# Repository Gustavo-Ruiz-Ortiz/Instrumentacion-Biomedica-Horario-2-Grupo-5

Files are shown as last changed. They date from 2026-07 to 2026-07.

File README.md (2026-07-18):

# Instrumentacion-Biomedica-Horario-2-Grupo-5

Sistema portátil de triaje cardiopulmonar con corrección por altitud - HealthyPi 5 / RP2040


## Tabla de contenidos

- [Equipo](#equipo)
- [Descripción del proyecto](#descripción-del-proyecto)
- [Problema que resuelve](#problema-que-resuelve)
- [Características principales](#características-principales)
- [Arquitectura del sistema](#arquitectura-del-sistema)
- [Stack tecnológico](#stack-tecnológico)
- [Estructura del repositorio](#estructura-del-repositorio)
- [Instalación y uso](#instalación-y-uso)
- [Resultados de validación](#resultados-de-validación)
- [Roadmap](#roadmap)

---
## Equipo — Grupo 5

| Integrante | Aporte principal |
|---|---|
| Aldo David Manturano Lopez | Desarrollo de la adquisición de señales, impresión 3D y electrónica del dispositivo|
| David Eddy Aguilar Yahuana | Desarrollo de la adquisición de señales, soporte bibliográfico |
| Juan Raul Ramirez Mendoza | Desarrollo de página web y filtrado de señales |
| Alejandra Ivonne Gamarra Leyva | Desarrollo del contexto de uso, problemática y justificación bibliográfica, lista de exigencias, diseño y modelado 3D del enclosure.|
| Davidt Brayamn Fernandez Bernaola | Desarrollo del contexto problemático y su estructura de funciones general, además de ello, gestionar el uso del dispositivo en escenarios de uso real.|
| Gustavo Andre Ruiz Ortiz | Programación e integración de sensores; flasheo y reprogramación del firmware (Python y Zephyr) para el ajuste de lectura de altitud y la reinterpretación de SpO2 según altitud; diseño e implementación del filtrado digital de señales, y ejecución de las pruebas de validación de la parte electrónica del sistema. Desarrollo del repositorio de GitHub. |

---

## Descripción del proyecto

Dispositivo portátil, autónomo y totalmente offline para el triaje cardiopulmonar en puestos de salud rurales de altura (>2500 msnm), desarrollado sobre la plataforma HealthyPi 5 (RP2040). Adquiere ECG, PPG/SpO2 y frecuencia respiratoria derivada, y reinterpreta automáticamente los valores según la altitud real del punto de atención, evitando falsas alarmas de hipoxia propias de los monitores calibrados a nivel del mar.

Proyecto desarrollado en el curso de Instrumentación Biomédica, Universidad Peruana Cayetano Heredia (UPCH) — Grupo 5.

## Problema que resuelve

Los puestos de salud rurales altoandinos enfrentan dos limitaciones simultáneas que ningún equipo comercial resuelve en conjunto:

| Limitación | Consecuencia |
|---|---|
| Monitores calibrados a nivel del mar | Falsas alarmas de hipoxia en población aclimatada a la altura |
| Infraestructura eléctrica y conectividad inestables/inexistentes | Los equipos dependientes de nube, WiFi o smartphone no son viables |

## Características principales

- ECG (derivación II de Einthoven) mediante chip MAX30001
- PPG / SpO2 mediante chip AFE4400 (660 nm rojo / 905 nm infrarrojo)
- Frecuencia respiratoria derivada del ECG por neumografía de impedancia transtorácica, sin sensores adicionales
- Corrección automática por altitud en tiempo real (sensor atmosférico BME280) usando percentiles poblacionales de referencia
- Operación 100% offline: visualización en pantalla TFT + almacenamiento local en MicroSD
- Plataforma web de post-análisis en Python/Streamlit con filtrado digital de señal (Notch IIR 60 Hz + Butterworth pasa-bajas) y control de acceso por token OTP
- Batería de Litio 3.7V/2500 mAh — 17 horas de autonomía (~200 sesiones de triaje)
- Diseño conforme a IEC 60601-1-11 (seguridad eléctrica en entornos sin conexión a tierra confiable)
- Enclosure diseñado en Fusion 360 e impreso en 3D (PLA)

## Arquitectura del sistema



## Stack tecnológico

| Capa | Tecnología |
|---|---|
| Microcontrolador | RP2040 (HealthyPi 5) |
| Firmware | Zephyr RTOS |
| Adquisición biopotenciales | MAX30001 |
| Adquisición PPG/SpO2 | AFE4400 |
| Sensor ambiental | BME280 (altitud) |
| Almacenamiento embebido | MicroSD |
| Post-procesamiento | Python, filtros digitales (Notch IIR, Butterworth) |
| Interfaz de usuario web | Streamlit |
| Seguridad de acceso | Tokens OTP |
| Diseño mecánico | Fusion 360 + impresión 3D (PLA) |
| Normativa | IEC 60601-1-11 |

## Estructura del repositorio

```
Instrumentacion-Biomedica-Horario-2-Grupo-5/
├── firmware/            # Código Zephyr para HealthyPi 5 (RP2040)
│   ├── src/
│   └── boards/
├── interfaz-python/     # Aplicación Streamlit de post-análisis
│   ├── app.py
│   ├── filtros.py
│   └── auth_otp.py
├── diseño-mecanico/     # Archivos Fusion 360 / STL del enclosure
├── docs/                # Informes, diagramas y datasheets
│   ├── Informe4_g5.docx
│   └── Informe5_6_Grupo5.docx
├── resultados/          # Capturas de pruebas de validación (OpenView 2)
├── .gitignore
└── README.md
```

## Instalación y uso

### Firmware (Zephyr / RP2040)

```bash
git clone https://github.com/Gustavo-Ruiz-Ortiz/Instrumentacion-Biomedica-Horario-2-Grupo-5.git
cd Instrumentacion-Biomedica-Horario-2-Grupo-5/firmware
west build -b healthypi5 .
west flash
```

### Interfaz Python (post-análisis)

```bash
cd interfaz-python
python -m venv .venv
source .venv/bin/activate      # Windows: .venv\Scripts\activate
pip install -r requirements.txt
streamlit run app.py
```

## Resultados de validación

Prueba de adquisición en banco (5 min continuos, sujeto sano, línea base a nivel del mar):

| Señal | Resultado | Método |
|---|---|---|
| ECG | 92 BPM estable | Detección de intervalo R-R, amplitud promedio 1.2 mV |
| SpO2 | 98% | PPG, sensor de pinza dactilar |
| Frecuencia respiratoria | 41 RPM | Neumografía por impedancia transtorácica derivada del ECG |

Se caracterizó además un artefacto de movimiento inducido intencionalmente, validando la etapa de filtrado digital implementada en la interfaz Python.

## Roadmap

- [ ] Filtros adicionales para artefactos de movimiento en PPG
- [ ] Validación clínica con mayor número de pacientes
- [ ] Estudio de mercado formal
- [ ] Evaluación de manufactura escalable del enclosure
- [ ] Trámite de protección de la invención ante la OPI-UPCH

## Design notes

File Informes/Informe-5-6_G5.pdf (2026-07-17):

## UNIVERSIDAD PERUANA CAYETANO HEREDIA

## INGENIERÍA BIOMÉDICA

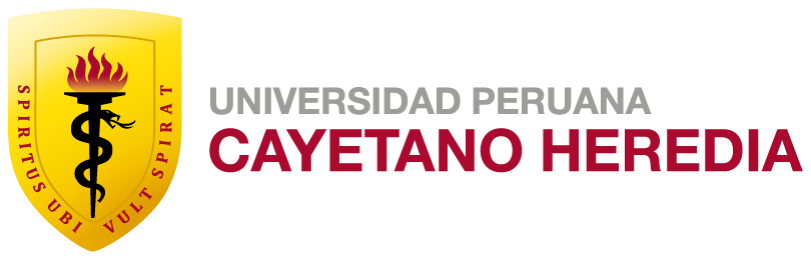
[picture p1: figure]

# PRÁCTICA DE INSTRUMENTACIÓN BIOMÉDICA

## Presentación del circuito impreso de la solución propuesta (PCB) y Solicitud de fabricación y Presentación final del modelo 3D del sistema completo [Práctica N°5 y N°6]

GRUPO N°: 5

Nombre de los Integrantes y código:

# - Aldo David, Manturano Lopez - 72387388 - David Eddy, Aguilar Yahuana - 71421807 - Juan Raul, Ramirez Mendoza - 72642526 - Alejandra Ivonne, Gamarra Leyva - 72771921 - Davidt Brayamn, Fernandez Bernaola - 72165022 - Gustavo Andre, Ruiz Ortiz - 72899306

2026 -1

### 1. Integración del sistema de diseño contextual

1.1. Problema clínico- tecnológico

Los puestos de salud rurales altoandinos carecen de especialistas y equipos

biomédicos calibrados para la fisiología de altura, imposibilitando un triaje

cardiopulmonar oportuno, por lo que exige un sistema portátil, autónomo y

adaptativo que optimice la toma de decisiones del personal no especialista en

el punto de atención.

1.2. Usuario objetivo y contexto de uso
1.2.1. Usuario paciente

Adultos de entre 18 y 60 años residentes de zonas altoandinas (2500 -

4000) msnm. Asimismo, debe ser originario de la localidad o demostrar

una residencia continua mayor a un año, asegurando que su organismo

haya completado los mecanismos de aclimatación crónica.

1.2.2. Usuario operador

Personal de salud de primer nivel de atención (técnicos en enfermería

o enfermeros rurales) sin especialización en cardiología o neumología.

1.2.3. Contexto de uso

El dispositivo está diseñado para operar en los establecimientos del

Primer Nivel de Atención (Categorías I-1 al I-4) en zonas rurales

altoandinas para brindar chequeos preventivos y triaje rápido.

1.3. Variables fisiológicas seleccionadas
1.3.1. Frecuencia cardiaca y frecuencias respiratoria

Tras analizar el artículo sobre los valores fisiológicos en la región de

Cajamarca y contrastarlos con los rangos normales estándar

establecidos por instituciones como la Cleveland Clinic, se concluye

que existe una notable adaptación de la frecuencia respiratoria (FR) y

frecuencia cardíaca (FC) en habitantes con 1 año mayor de estancia

en una localidad.

De acuerdo a la FR según la referencia de la Cleveland Clinic, el rango

normal para un adulto es de 12 a 18 respiraciones por minuto [1]. Al

observar la Tabla 4 del artículo, se evidencia que en altitudes

moderadas como 1,294 msnm, la media es de 17.53. Aunque a

altitudes mayores como 3,502 msnm la media sube ligeramente a

20.32, los valores se mantienen muy cerca de los límites superiores de

la normalidad estándar [2]. Esto sugiere que, tras más de un año de

residencia, la aclimatación permite que la FR no se dispare de forma

patológica. Por otro lado, la frecuencia cardiaca su rango normal

estándar se sitúa entre 60 y 100 latidos por minuto, los datos del

estudio en Cajamarca muestran que independientemente de la altitud

todas las medias registradas están dentro de este margen clínico.

1.3.2. Saturación de oxígeno

Para obtener la lectura correcta de Sp02 del paciente, se está optando

por realizar una reinterpretación de la lectura del Sp02 de acuerdo a la

altitud que se encuentre el paciente. Para ello se está usando los

valores del artículo [3] que se basa en percentiles, los datos que se

extrajeron de la imagen de nuestro público objetivo fue con el software

en línea automeris.io, asimismo, se está haciendo el uso de la técnica

de interpolación lineal para obtener lecturas para diferentes alturas y

por último, para obtener la lectura de la altura exacta donde se

encuentra el dispositivo es a través del sensor BMP280 Qwiic. A

continuación se presenta el siguiente flujo.

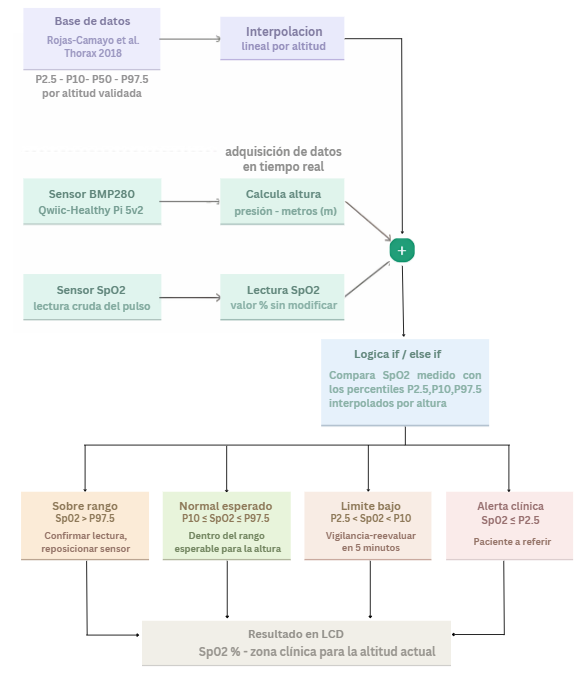
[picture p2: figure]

Fig.1. Flujo de Sp02

1.4. Señales de HelthyPi 5 utilizadas

1.4.1. AFE4400 SpO2

La señal de fotopletismografía (PPG) es capturada mediante un sensor

óptico externo y procesada por el chip AFE4400, que actúa como el

Front-End Analógico (AFE) del sistema [4], permitiendo convertir los

datos analógicos en datos digitales precisos, permitiendo así el cálculo

de la saturación de oxígeno por parte del procesador central

1.4.2. MAX30001 ECG BioZ Frontend

El ECG es adquirido por el chip MAX30001 el cual es un AFE (Analog

Front End) que detecta las diferencias de potencial eléctrico generadas

por la despolarización y repolarización del músculo cardíaco a través

de electrodos de superficie colocados en el tórax del paciente [4]. Por

lo tanto la FR se obtiene como señal derivada del ECG mediante la

técnica de Neumografía por Impedancia Transtorácica.

1.5. Ruta técnica

Esta ruta corresponde al sistema desplegado en el puesto de salud rural, este

diseño elimina toda dependencia de infraestructura externa con el objetivo de

presentar autonomía en zonas remotas y simplicidad operativa en el triaje del

paciente. Componentes de la ruta:

1. Adquisición de señales
2. Procesamiento embebido
3. Visualización en pantalla TFT
4. Registro local MicroSD
5. Post-procesamiento MicroSD

El procesamiento embebido en la placa y la visualización en pantalla TFT

elimina la dependencia de un PC o conexión a internet, esto garantiza que el

equipo sea portátil y operativo en cualquier puesto de salud de primer nivel.

1.6. Diagrama de integración del sistema

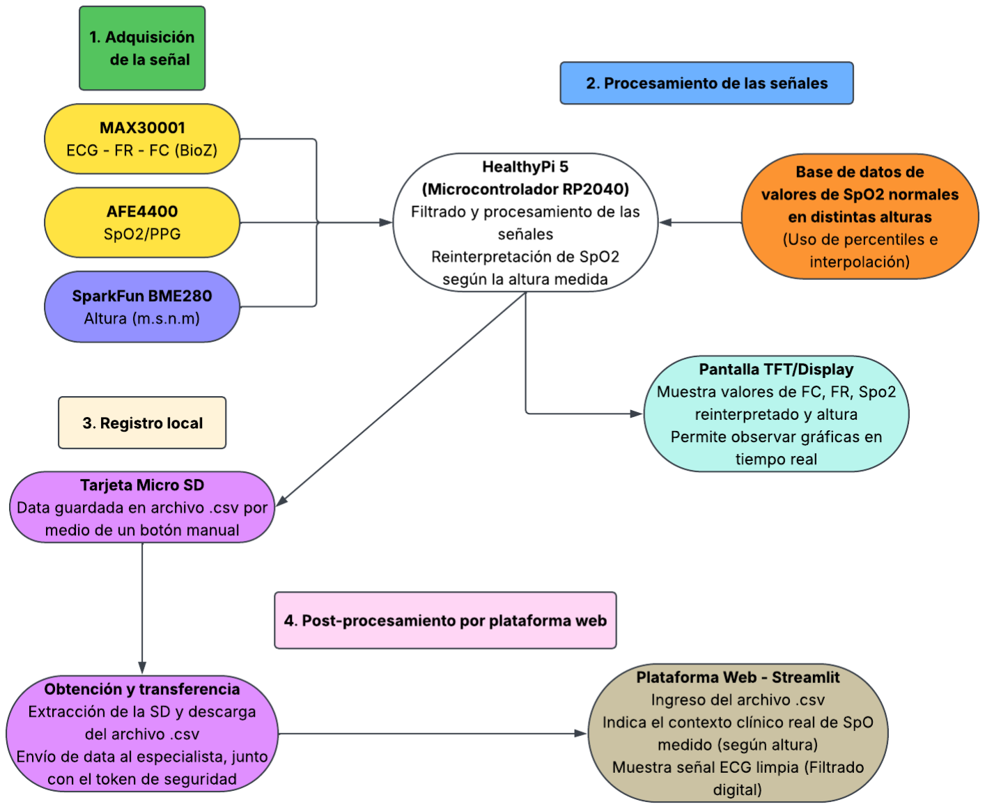
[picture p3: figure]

1.7. Lista de exigencias

Fecha | Deseo o exigencia | Descripción | Responsable
03/06/26 | E | Precisión esperada: Las señales adquiridas deberán tener una calidad suficiente y un buen manejo del ruido para estimar las variables de frecuencia cardíaca, frecuencia respiratoria y saturación de oxígeno de manera confiable. El sistema deberá estimar la frecuencia cardíaca con un error máximo de ±3 bpm; la frecuencia respiratoria con ±2 rpm y el SpO2 con un error máximo de ±2%. | Alejandra, Gustavo
03/06/26 | E | Portabilidad: El sistema debe ser liviano y resistente, de uso portátil y fácil de transportar de forma segura, considerando que será usado en zonas alejadas del país para permanecer como un equipo de evaluación puntual. | Gustavo
03/06/26 | E | Energía: El sistema deberá funcionar mediante alimentación interna por baterías recargables. | Aldo, Juan
03/06/26 | E | Autonomía: La duración del sistema de triaje es de 17 horas antes de necesitar una recarga de batería. El tiempo estimado por sesión de triaje es de 5 minutos, con un aproximado de 200 sesiones por recarga del dispositivo. | Alejandra
03/06/26 | E | Electrónica: El sistema usará la plataforma Healthy Pi 5, el MAX30001 Y el AFE4400 para la adquisición de las señales. | Gustavo, Alejandra
03/06/26 | E | Seguridad: El sistema deberá trabajar de acuerdo a la normativa de seguridad eléctrica IEC 60601-1-11, con niveles seguros de alimentación y un factor de corrección adecuado para evitar riesgo eléctrico. Además, los componentes del sistema deberán soportar caídas sobre superficies duras y las condiciones propias de zonas de altura como bajas temperaturas. | David, Brayamn
03/06/26 | D | Ergonomía: El uso del sistema en el usuario, la colocación de los electrodos y la interfaz de entrega de resultados deberán ser intuitivos y cómodos para el usuario. | Alejandra
03/06/26 | D | Costo: El diseño deberá considerar principalmente componentes accesibles y priorizar un sistema de bajo costo. | David
03/06/26 | E | Almacenamiento: El sistema podrá guardar los registros de las señales y permitir que pueda compartirse posteriormente. | Juan
03/06/26 | E | Visualización: El sistema deberá permitir la | Brayamn

### 2. Justificación técnica para la exclusión del diseño y fabricación de PCB

El diseño y la manufactura de una placa de circuito impreso (PCB) personalizada es

técnicamente innecesaria y contraproducente para los objetivos del proyecto. El

sustento de esta decisión se detalla bajo los siguientes argumentos:

2.1. Modularidad ya Integrada en la placa HealthyPi v5

La plataforma central HealthyPi es un sistema integrado robusto que ya posee

los Front-Ends analógicos específicos, MAX30001 para ECG/BioZ y AFE4400

para SpO2 ruteados internamente asegurando la integridad de la señal

medida.

Los sensores biomédicos como el electrodo de ECG y clip de dedo SpO2

utilizan conectores normalizados de fábrica soldados directamente a la placa

principal.

2.2. Ecosistema estándar Qwiic para expansión de sensores

La adición del sensor atmosférico SparkFun BME280 se resuelve de manera

nativa mediante el protocolo de comunicación I2C a través del conector Qwiic,

eliminando la necesidad de placas de interfaz, soldadura o lógica de

acondicionamiento de señales adicionales.

Asimismo, la placa HealthyPi ya provee las líneas de alimentación regulada

3.3V y GND compartidas con la impedancia de acople correcta para el correcto

y seguro funcionamiento.

2.3. Gestión de Energía y autonomía

El requerimiento crítico de portabilidad y alimentación se encuentra resuelto

de manera nativa por el hardware del sistema. La placa HealthyPi incluye un

circuito integrado de gestión de carga de baterías de Li-Po y un puerto USB

Tipo-C para su respectiva carga.

visualización clara de las señales procesadas en una pantalla TFT.

Es importante resaltar que durante la fase de triaje médico preventivo en

campo, se debe asegurar la desconexión física del cable USB-C de

alimentación de la red y el uso exclusivo del conector de batería, de esta

manera garantizar el aislamiento eléctrico total del paciente y obtener señales

no interferidas por ruido eléctrico 50/60 Hz.

Al demostrarse que el prototipo es 100% funcional acoplando los módulos de fábrica

por cableado, se eliminan formalmente las siguientes actividades del cronograma por

no aplicar al alcance del proyecto:

1. Alcance de la PCB propuesta: Reemplazado por el alcance del acople

modular que provee la placa HealthyPi

2. Esquemático en EasyEDA: Innecesario, ya que se usan los esquemáticos de

hardware abierto oficiales de ProtoCentral y SparkFun (BME280).

3. Plan de adquisición de componentes: Reducido únicamente a la compra de

los módulos comerciales externos como el sensor SparkFun (BME280).

4. Diseño del circuito impreso en EasyEDA: Excluido por ausencia de circuito

personalizado.

5. Justificación del layout de PCB: Excluido.
6. Verificación del diseño: Reemplazado por la verificación de continuidad y

bus de comunicación I2C mediante el software.

7. Generación de archivos de fabricación (Gerbers): Excluido.
8. Previsualización de fabricación en JLCPCB: Excluido.

### 3. Modelo 3D del sistema completo

El modelo 3D del enclosure del sistema fue diseñado en Fusion 360. Se decidió que

el dispositivo no incluya la PCB diseñada previamente por motivos de practicidad en

el diseño final. Además, el enclosure incluye un espacio permanente para el Healthy

Pi 5 y su pantalla, considerando a estos componentes integrados y no destinados a

ser removidos, como se observa en la Figura 1 y 2. La Figura 3 y la Figura 4

muestran las aberturas consideradas en el modelo para el fácil manejo del sistema.

Las aberturas del lado derecho están destinadas para los sensores del Healthy Pi,

mientras que los del lado izquierdo existen para el manejo de la pantalla, tanto el

switch de encendido como la rueda de cambio, y para el del módulo TP4056

destinado a la carga del sistema. La Figura 6 muestra la vista isométrica del modelo abierto, donde se puede apreciar el espacio destinado a la batería, que cuenta con

una tapa unida por medio de encastre. Las Figuras 12 y 13 muestran claramente los

dos tipos de fijación considerados; ambas partes principales del enclosure encajan

por medio de encastre, sin embargo, también se considera el uso de tornillos para

asegurarlas de forma correcta. La Figura 14, por otro lado, muestra los espacios

destinados a los componentes adicionales, el módulo TP4056 y el BME280,

diseñados para estar encajados por medio de tornillos. Finalmente, el modelo final

del enclosure tiene un mango de sujeción para facilitar la ergonomía del diseño; a su

vez, el tamaño pequeño y peso ligero es ideal para su portabilidad y sujeción por

parte del usuario operario.

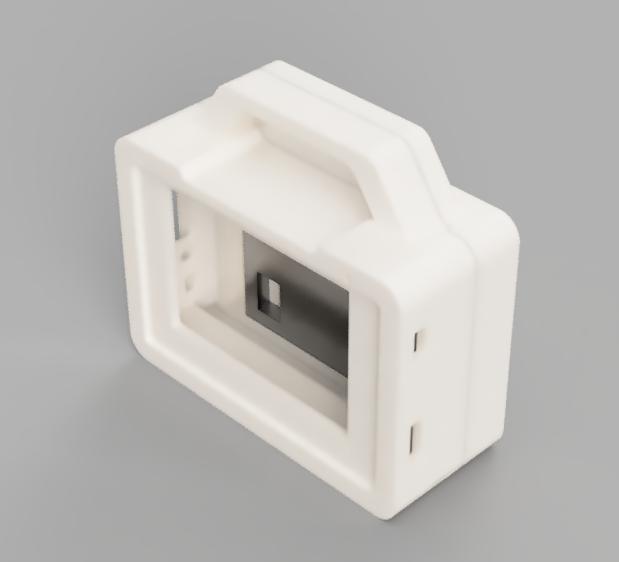
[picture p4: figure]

Figura 1. Vista isométrica del modelo 3D renderizado

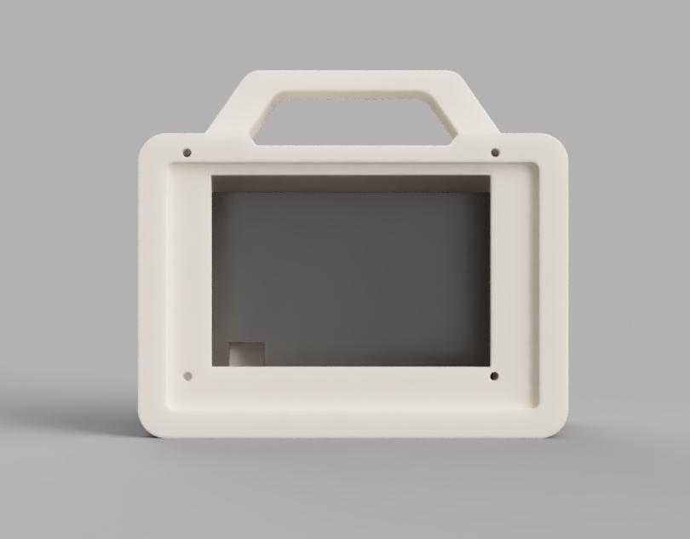
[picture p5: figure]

Figura 2. Vista frontal del modelo 3D renderizado

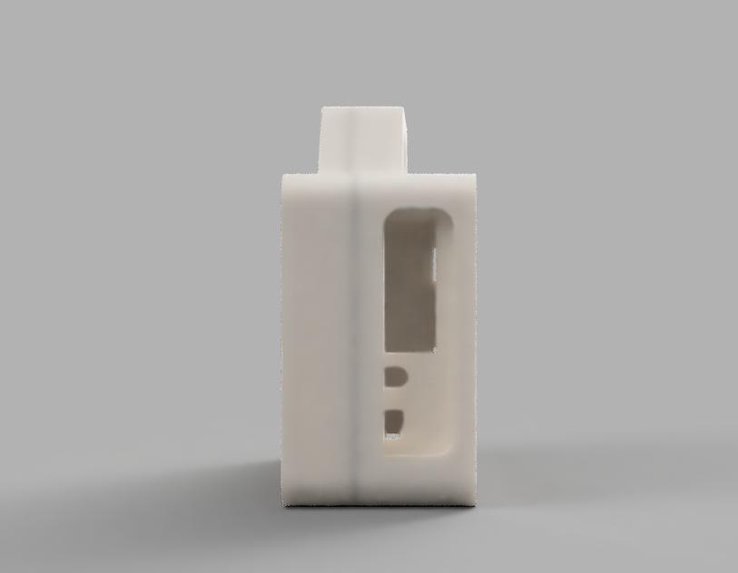
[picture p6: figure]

Figura 3. Vista lateral derecha del modelo 3D renderizado

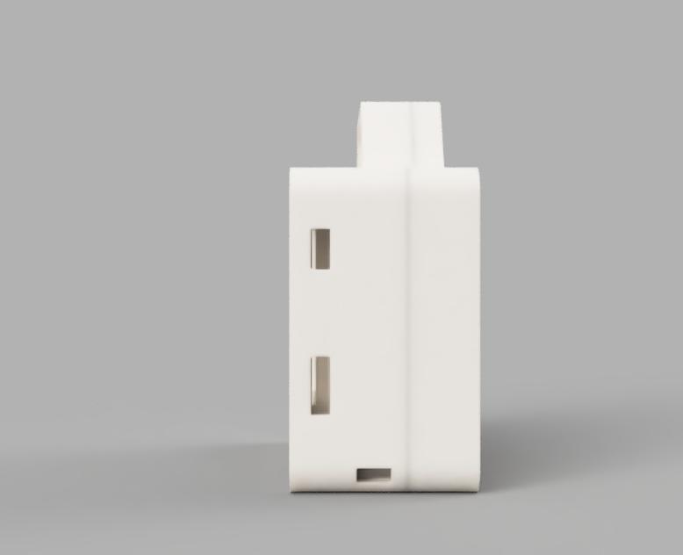
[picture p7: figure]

Figura 4. Vista lateral izquierda del modelo 3D renderizado

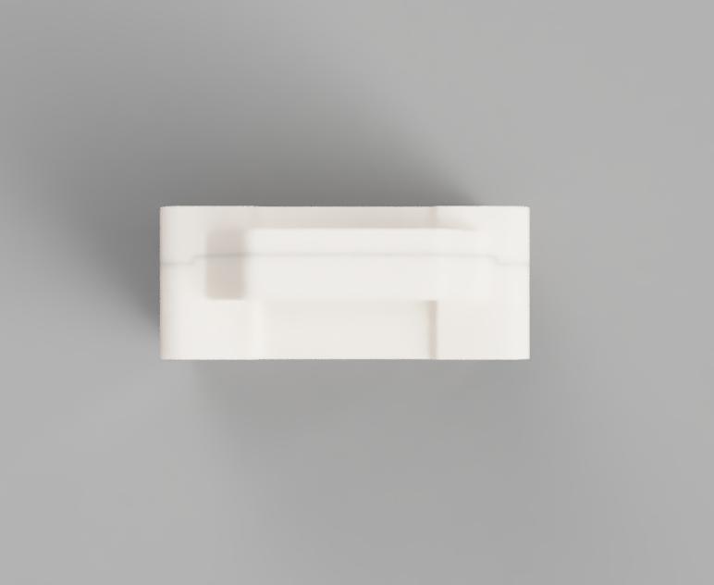
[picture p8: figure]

Figura 5. Vista superior del modelo 3D renderizado

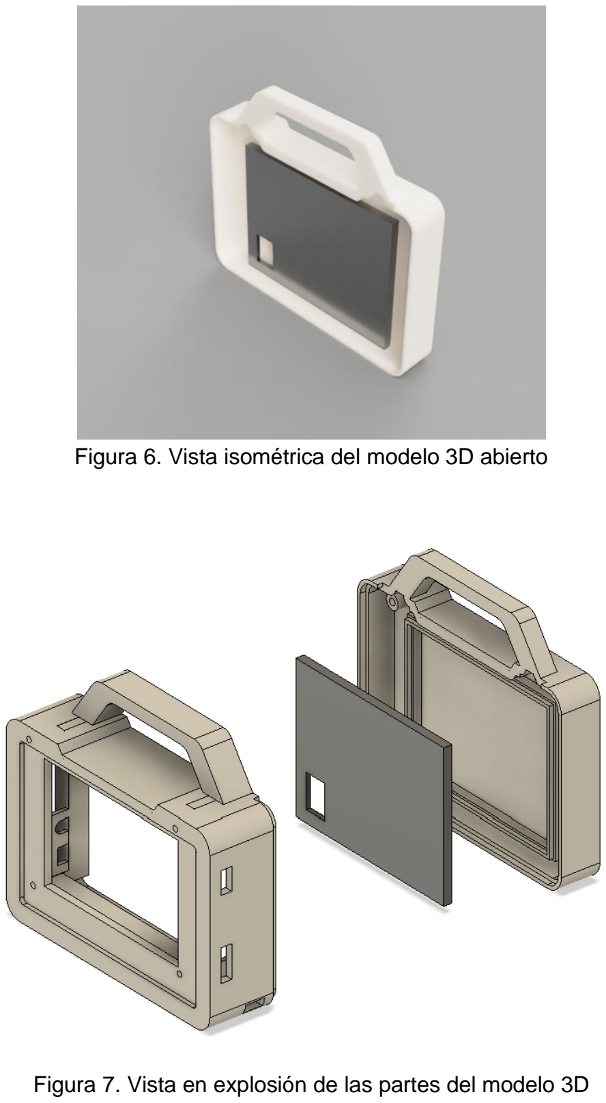
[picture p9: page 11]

Figura 6. Vista isométrica del modelo 3D abierto

Figura 7. Vista en explosión de las partes del modelo 3D

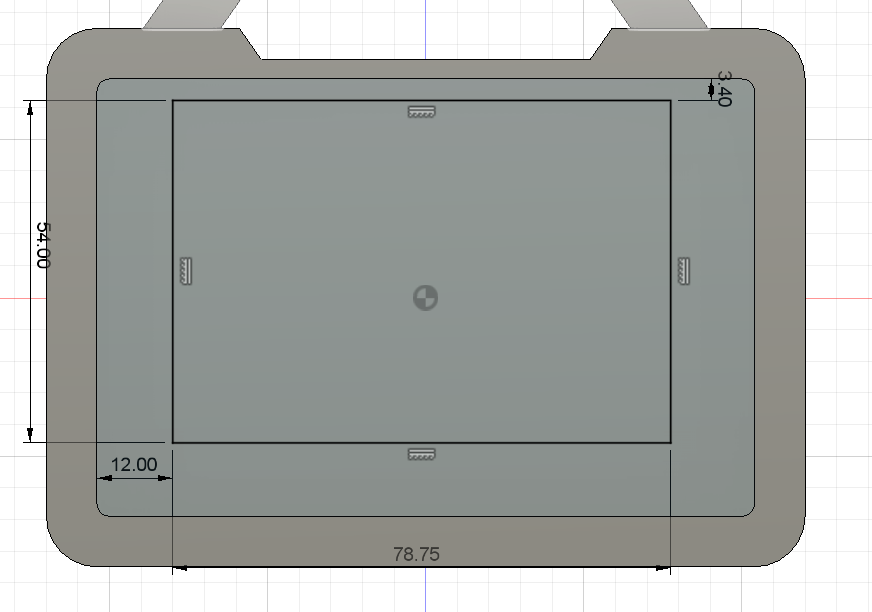
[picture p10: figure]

Figura 8. Dimensiones en vista frontal del espacio para la pantalla TFT

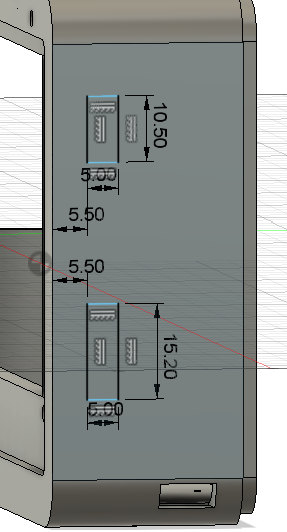
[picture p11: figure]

Figura 9. Dimensiones laterales izquierdas para el switch y rueda de la pantalla

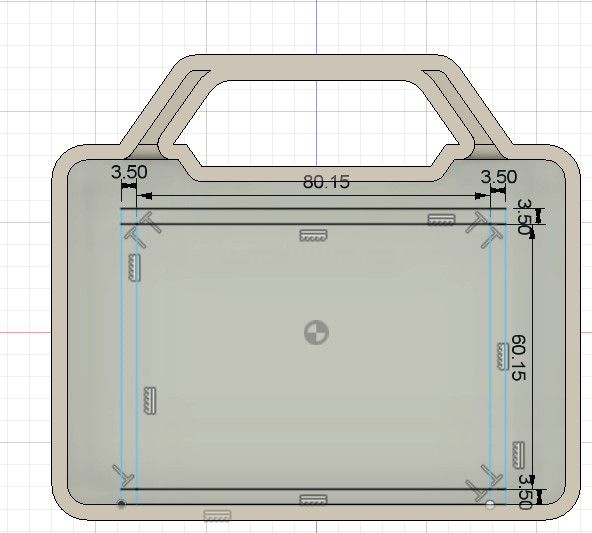
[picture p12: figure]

Figura 10. Dimensiones del enclosure interno para la batería

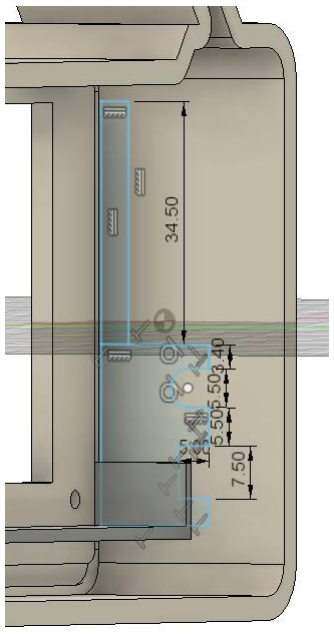
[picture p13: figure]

Figura 11. Dimensiones de las aberturas del lado derecho

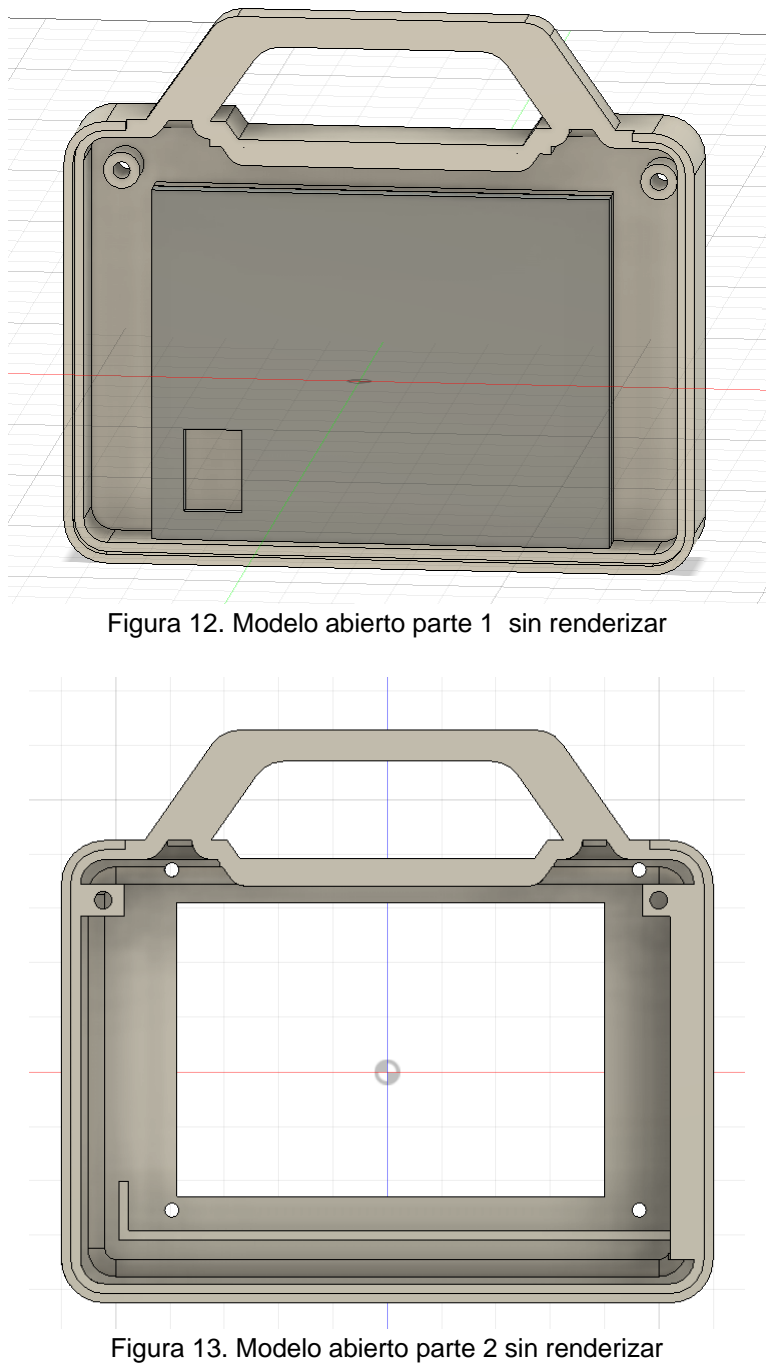
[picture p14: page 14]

Figura 12. Modelo abierto parte 1 sin renderizar

Figura 13. Modelo abierto parte 2 sin renderizar

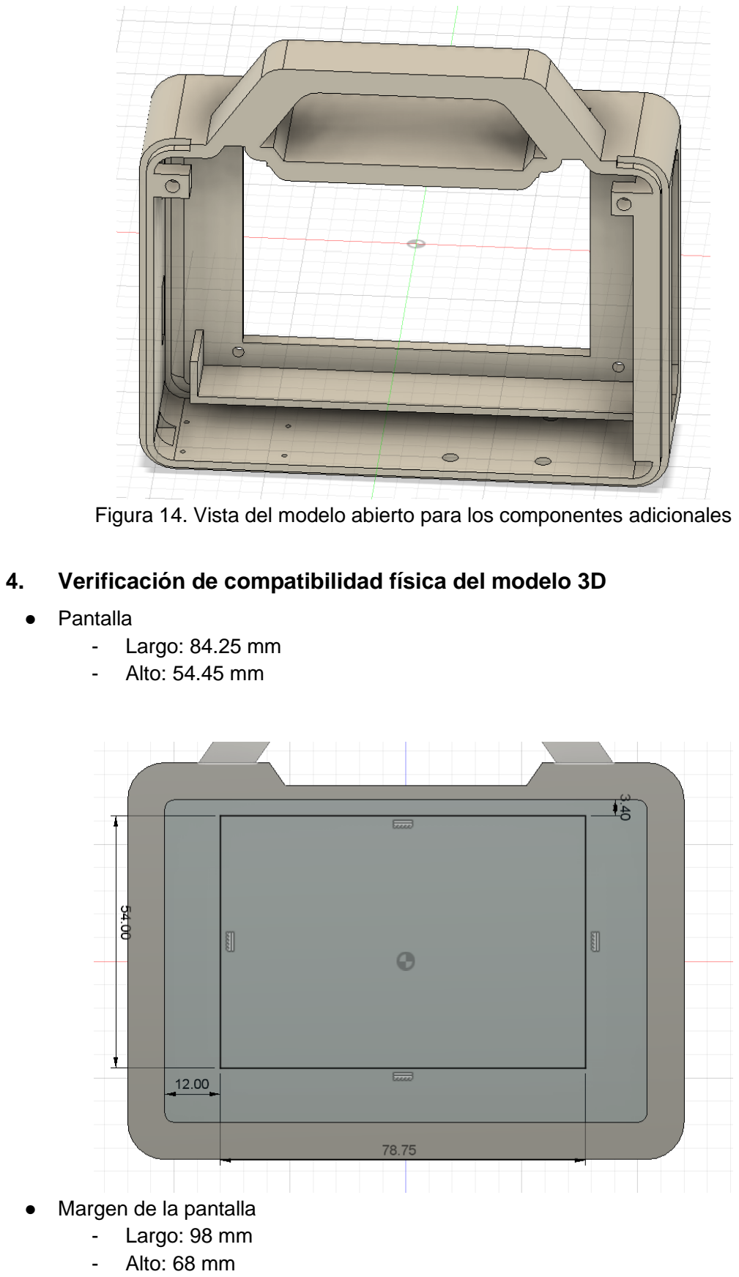
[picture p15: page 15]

Figura 14. Vista del modelo abierto para los componentes adicionales

### 4. Verificación de compatibilidad física del modelo 3D

- Pantalla
- Largo: 84.25 mm
- Alto: 54.45 mm
- Margen de la pantalla
- Largo: 98 mm
- Alto: 68 mm

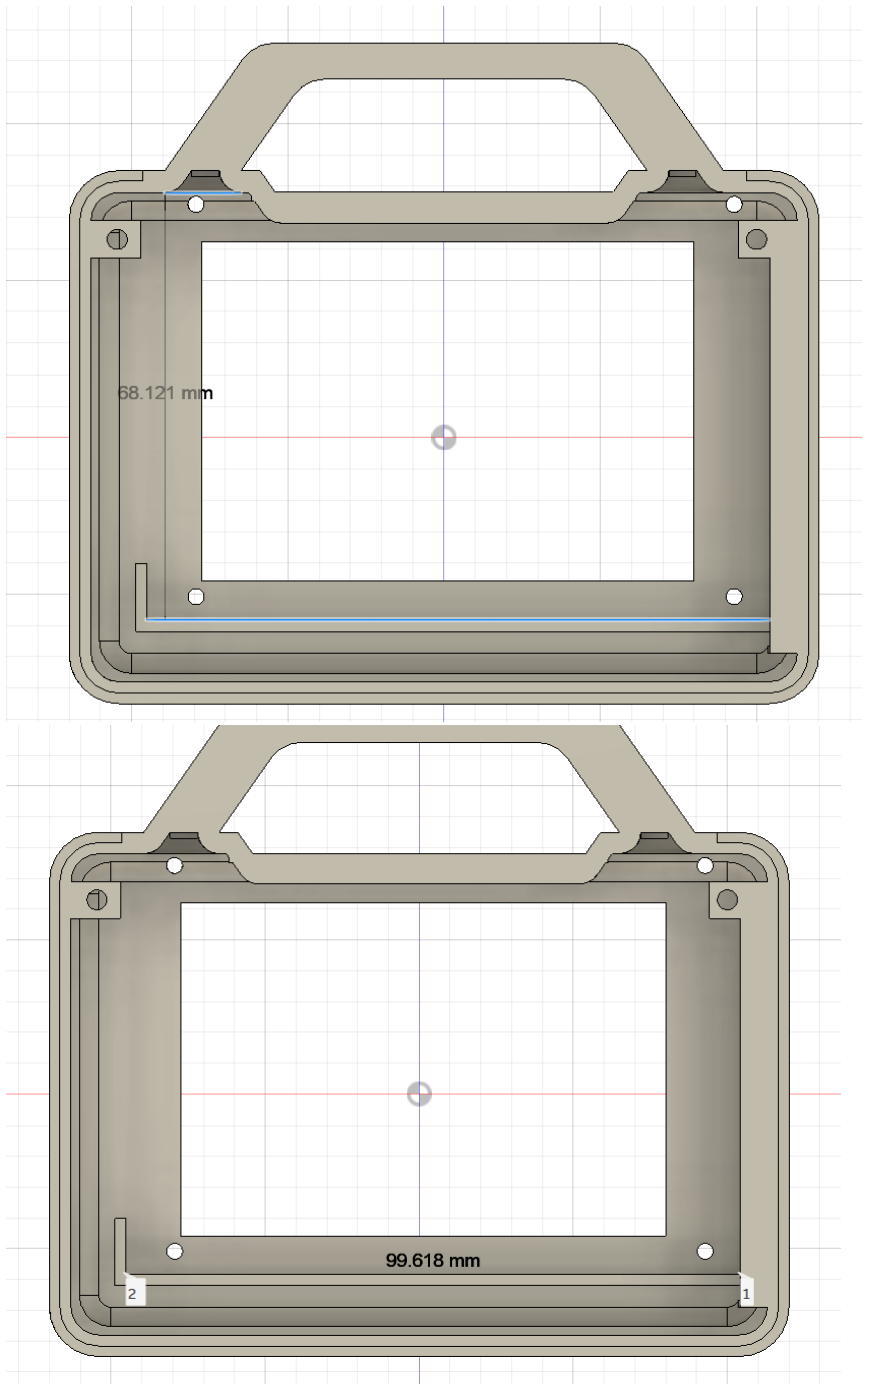
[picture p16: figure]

- Healthy Pi
- Largo: 75.5 mm
- Alto: 56 mm
- Agujero: 2.6 mm

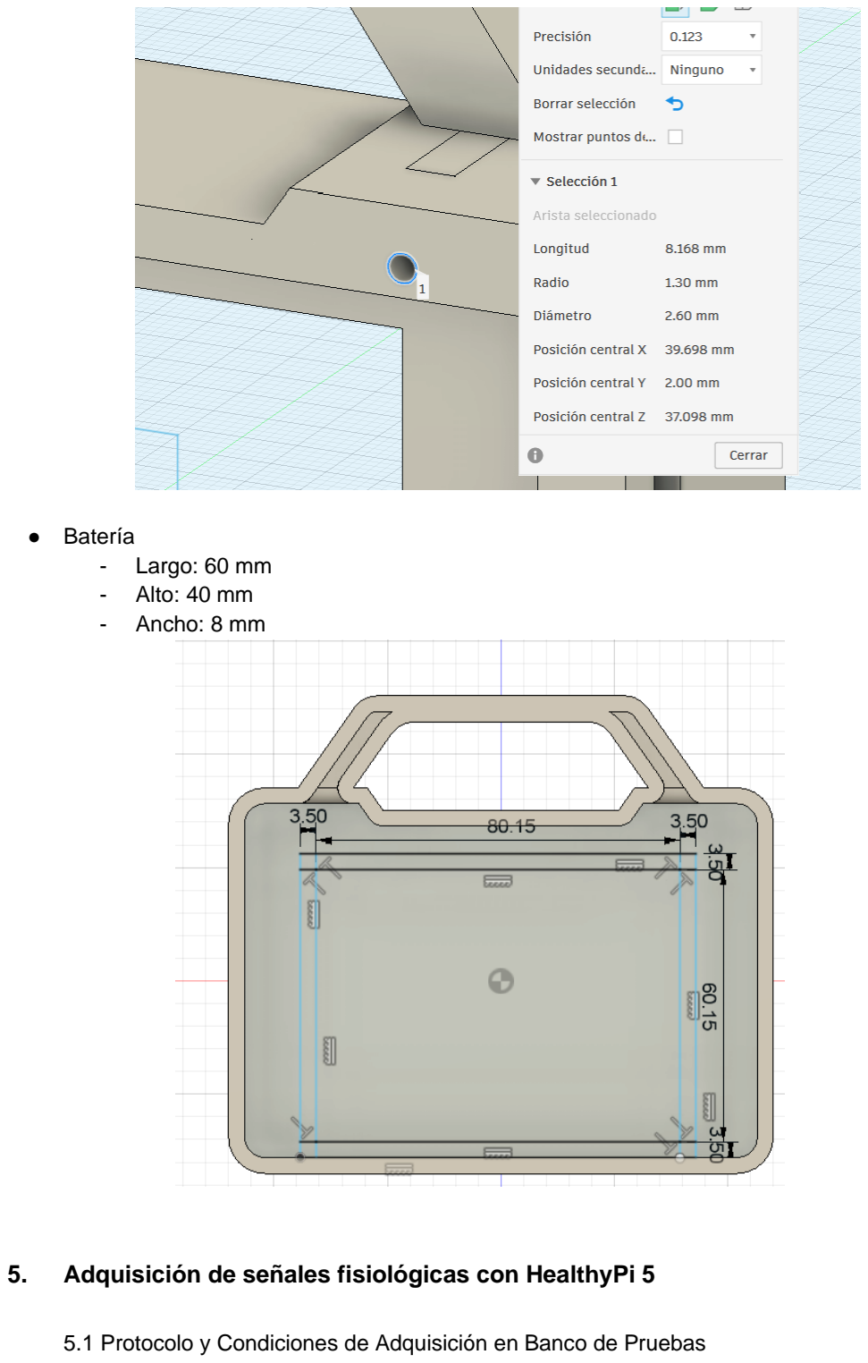
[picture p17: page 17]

- Batería
- Largo: 60 mm
- Alto: 40 mm
- Ancho: 8 mm

### 5. Adquisición de señales fisiológicas con HealthyPi 5

5.1 Protocolo y Condiciones de Adquisición en Banco de Pruebas

Para demostrar el funcionamiento inicial de la plataforma de adquisición antes de su

encapsulamiento y validar la viabilidad del volcado de datos que posteriormente leerá

la interfaz en Python, se realizó una prueba de registro real en un entorno controlado

bajo los siguientes parámetros:

5.1.1 Identificación del Sujeto: Voluntario sano (residente crónico en zona

costera, tomado como línea base de calibración).

5.1.2 Duración del Registro Continuo: 5 minutos de adquisición no interrumpida

5.2 Sensores e Instrumentación Utilizados:

5.2.1 Canal de ECG y Respiración (Módulo MAX30001 integrado):

Configuración de 3 electrodos de superficie desechables de Ag/AgCl

colocados en la disposición de la Derivación II de Einthoven (Brazo Derecho -

RA, Pierna Izquierda - LL, y Referencia en Pierna Derecha - RL). Esta vía

registra en simultáneo el biopotencial cardíaco y la neumografía por

impedancia torácica.

5.2.2 Canal de PPG y SpO₂ (Módulo AFE4400 integrado): Sensor óptico de

pinza reutilizable con dos longitudes de onda (Rojo a 660 nm e Infrarrojo a 905

nm) colocado en el dedo índice de la mano derecha.

5.3 Captura del Entorno de Adquisición

La visualización y captura de los vectores biopotenciales crudos en bruto (Raw Data)

se gestionó mediante el software oficial OpenView 2, configurado para comunicación

serie directa con la placa de desarrollo a través de un canal aislado, garantizando la

seguridad eléctrica del voluntario.

5.4 Resultados del Registro y Extracción de Variables Clínicas

Durante la ventana de observación estable en el software de instrumentación, se

obtuvieron y calcularon las siguientes variables fisiológicas en tiempo real:

5.4.1 Señal Electrocardiográfica (ECG - Derivación II): La onda presenta una

morfología limpia donde el complejo QRS es poco distinguible, con una

amplitud promedio de 1.2 mV. A partir de la detección automática de la

distancia entre los picos R (intervalo R-R), el sistema calculó una Frecuencia

Cardíaca estable de 92 BPM.

5.4.2 Onda Pletismográfica (PPG): Se visualizó una saturación de oxígeno

(SpO₂) basal de 98%, valor fisiológicamente esperado para un sujeto sano al

nivel del mar.

5.4.3 Señal de Respiración (RESP): La variación de la impedancia basal

torácica debida a los ciclos de inspiración y espiración permitió registrar una

curva senoidal lenta de baja frecuencia, de la cual se derivó una Frecuencia

Respiratoria de 41 RPM.

5.5 Comentario Técnico sobre la Calidad de la Señal y Limitaciones

5.5.1 Artefactos por Movimiento: Durante los primeros 10 segundos del

registro, se indujo un movimiento intencional en la mano derecha del

voluntario sano. Esto generó un artefacto de movimiento severo en la

onda PPG (saturación temporal del fotodiodo del AFE4400) y una

deriva transitoria de la línea base en el ECG. Este comportamiento

justifica técnicamente por qué la interfaz médica desarrollada en

Python requiere de la futura implementación de filtros digitales para

limpiar los trazos antes de emitir el diagnóstico de triaje.

### 6. Estado de la interfaz de usuario

6.1. | Arquitectura | de | Software | y | Entorno | de | Desarrollo

Para la visualización y análisis de los datos biomédicos, se diseñó una plataforma web

interactiva utilizando Python como lenguaje principal. El entorno de desarrollo local se

gestionó mediante Visual Studio Code, integrando librerías especializadas como pandas para el manejo de matrices de datos, scipy para el procesamiento digital de

señales, y plotly para el renderizado de gráficos interactivos. El despliegue de la

aplicación se realizó conectando un repositorio de GitHub a la plataforma Streamlit

Community Cloud, lo que permitió obtener un enlace público, permanente y accesible

desde cualquier dispositivo sin requerir instalaciones locales.

### 6.2. Flujo Operativo y Bioseguridad

Considerando el contexto rural y la baja conectividad, el flujo de trabajo establece que

el técnico extraiga los datos de la memoria MicroSD del sistema HealthyPi 5 y los

remita al médico especialista. Para garantizar la bioseguridad y la confidencialidad de

la información médica, se implementó un sistema de control de acceso mediante tokens dinámicos de un solo uso (OTP). La plataforma genera a través de algoritmos

matemáticos claves temporales válidas por ventanas de 15 minutos. Si el usuario

ingresa un token expirado o incorrecto, el sistema bloquea la carga de archivos; si es

correcto, el estado de sesión se autentica permitiendo un tiempo de análisis ilimitado

para el especialista.

### 6.3. Procesamiento de Señales y Contexto Clínico

Una vez cargado el documento .csv, el sistema despliega dos módulos principales:

- Módulo de Oximetría de Pulso: Calcula el promedio de la señal de SpO_2 y

aplica una lógica de contexto clínico basada en la altitud de la posta médica,

ajustando los percentiles de normalidad para evitar falsas alertas de hipoxia

en zonas altoandinas.

- Módulo de Actividad Eléctrica (ECG): Implementa una tubería de filtros

digitales para limpiar la señal cruda. Se aplica un filtro Notch IIR (60 Hz, Q=30)

para eliminar la interferencia de la red eléctrica, seguido de un filtro pasa-bajas

Butterworth de 4to orden (40 Hz) para atenuar el ruido muscular. Se utilizó la

técnica de fase cero (filtfilt) para preservar la alineación temporal de los

complejos QRS. El resultado se muestra en un gráfico interactivo que contrasta

la señal original con la filtrada.

Diagrama de Flujo

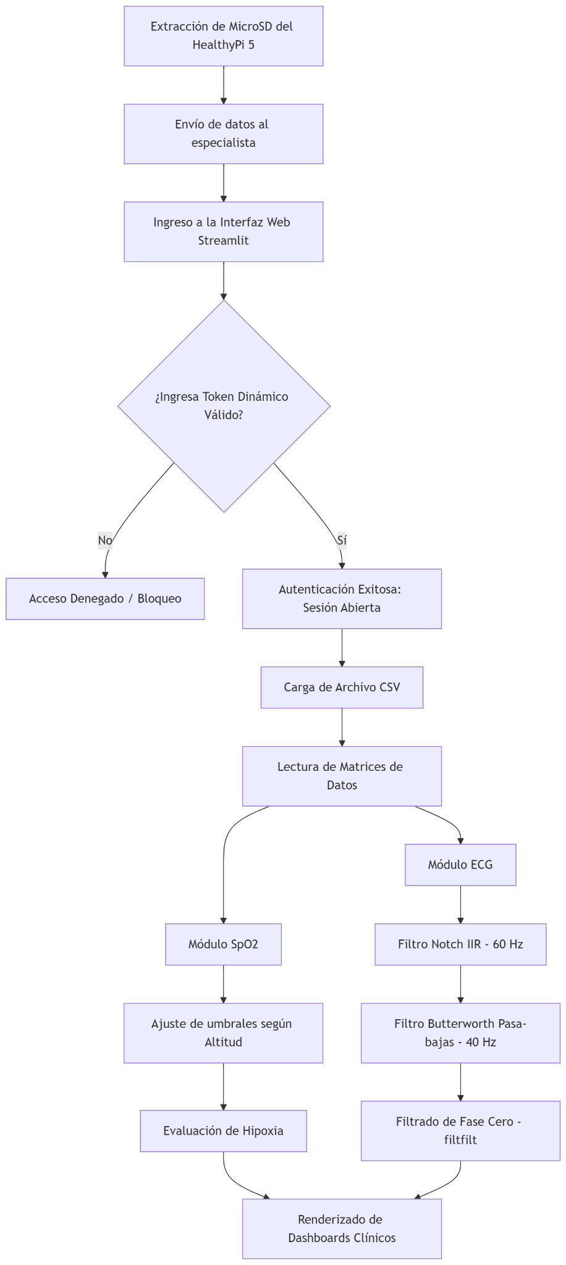
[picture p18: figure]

### 7. Adquisición de componentes

Componente / módulo | ¿Comprado ? | Proveedor | Fecha de llegada estimada | Observación
HealthyPi 5 (kit) | Si | Protocentral | 19/05/2026 | Se enciende correctamente, aunque presenta una sección en la esquina que no funciona
PCB fabricada | No | - | - | El uso de PCB no es necesario, ya que HealthyPi cumple lo que el prototipo busca
Pantalla / display | Si | Protocentral | 19/05/2026 | Funciona correctamente
Batería / fuente | Si | HI-FI S.A.C. | 25/06/2026 | Voltaje suficiente para las necesidades del prototipo
Carcasa / enclosure | No | Impresión 3D | 01/07/2026 | Se diseñó la carcasa del dispositivo, y será impreso en material PLA
Otros: Sensor atmosférico SparkFun (BME280) | Si | SparkFun Electronics | 16/05/2026 | Llegó sin ningún improvisto

### 8. Riesgos identificados y plan de acción

### 9. Bibliografía

[1]Cleveland Clinic, "Vital Signs," Cleveland Clinic, Jan. 21, 2024. [Online]. Disponible en: clevelandclinic.org. [Accedido: Jun. 25, 2026]

[2]Córdova-Castañeda, M. , Rimarachín-Chávez, A. , Linares-García, L. , López-Chegne, N. , Herrera-Flores, B. , Longa-Cerna, N. , Zavaleta-Gavidia, V. and Ortiz-Oblitas, P. (2025) Normal Physiological Values of Heart Rate, Respiratory Rate, Oxygen Saturation, Blood Pressure, and Hematocrit in Inhabitants of the Cajamarca Region Residing at Altitudes above 1000 Meters above Sea Level. World Journal of Cardiovascular Diseases, 15, 509-518. doi: 10.4236/wjcd.2025.1510045.

[3]J. Rojas-Camayo et al., “Reference values for oxygen saturation from sea level to the highest human habitation in the Andes in acclimatised persons,” Thorax, vol. 73, no. 8, pp. 776–778, Aug. 2018, doi: 10.1136/thoraxjnl-2017-210598.

[4] A. Whitchurch, “HealthyPi 5,” Crowd Supply, 4 de marzo de 2024. [En línea]. Disponible en: https://www.crowdsupply.com/protocentral/healthypi-5. [Accedido: Jun. 25, 2026]
Riesgo identificado | Impacto (Alto / Medio / Bajo) | Probabilidad (Alta / Media / Baja) | Acción de mitigación
Señales fisiológicas con ruido excesivo | Alto | Alta | Aplicación de filtros digitales para atenuar el ruido
Desconexión de sensor PPG | Medio | Medio | Verificar conexión del sensor, caso contrario, reemplazar por otro sensor
Señales en tiempo real demasiado lentas | Alto | Alta | Modificación del código del HealthyPi
Modelado 3D incompatible con las dimensiones del HealthyPi | Medio | Medio | Modificación del modelo para asegurar su correcto encaje
Interferencia del modelo 3D con los cables de los sensores | Alto | Medio | Modificación del modelo para asegurar espacio suficiente

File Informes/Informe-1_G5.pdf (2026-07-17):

## UNIVERSIDAD PERUANA CAYETANO HEREDIA

## INGENIERÍA BIOMÉDICA

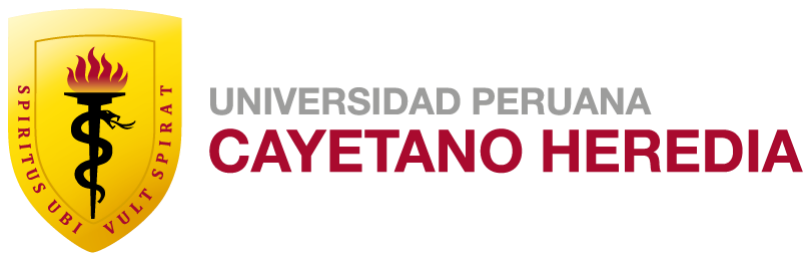
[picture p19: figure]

# PRÁCTICA DE INSTRUMENTACIÓN BIOMÉDICA

## Declaración y Validación Inicial de la Problemática Clínica y Tecnológica en

Dispositivos Biomédicos.

## [Práctica N°1]

GRUPO N°: 5

Nombre de los Integrantes y código:

# - Aldo David Manturano Lopez - 72387388 - David Eddy Aguilar Yahuana - 71421807 - Juan Raul Ramirez Mendoza - 72642526 - Alejandra Ivonne Gamarra Leyva - 72771921 - Davidt Brayamn Fernandez Bernaola - 72165022 - Gustavo Andre Ruiz Ortiz - 72899306

2026 -1

### 1. Delimitación del proyecto

### 1.1. Línea de proyecto

El proyecto elegido es: “Sistema de triaje cardiopulmonar portátil para

zonas rurales de altura”. Dentro de la Ingeniería Biomédica, la línea de

proyecto correspondiente es la adquisición y procesamiento de señales

de variables fisiológicas relevantes al sistema cardiorrespiratorio

mediante un dispositivo portátil para soporte hospitalario en zonas de

altura con recursos limitados.

### 1.2. Contexto de uso

Para delimitar el contexto de uso de este proyecto, se deben considerar

las condiciones y limitaciones geográficas. Se establece que las

características comunes de las zonas en las que se va a usar el

resultado del proyecto es que son rurales y de altura. Bajo esta

condición, se resalta que los parámetros de función cardiopulmonar y

los límites para determinar algún tipo de insuficiencia varían de acuerdo

al nivel de altitud del lugar en el que se encuentra el paciente, por lo que

la altura en el que el dispositivo es usado es una variable esencial para

una evaluación fisiológica inicial óptima y eficiente. Según el consenso

sobre la medicina crítica en la altitud de la Federación Panamericana e

Ibérica de Medicina Crítica y Terapia Intensiva, en alturas mayores a

1500 msnm, variables como la presión inspirada de oxígeno (PIO2) o la

saturación de oxígeno (SaO2) se encuentran disminuidas, y esta

disminución depende de la altitud, diferenciando entre la media altitud

(1.500 a 2.500 msnm), elevada altitud (2.500 a 3.500 msnm) y gran

altitud (3.500 a 5800 msnm). [1]

Además, el dispositivo va a ser usado en los puestos de salud de primer

nivel de estas zonas, lo que establece un uso hospitalario. Según un

estudio realizado en áreas rurales y urbanas, se estableció que las

áreas rurales presentan mayores barreras en el acceso a servicios de

salud, razón por la cual es relevante que se consideren los puestos de

primer nivel, que son los más cercanos a la población rural. La calidad

del servició de salud fue calificado como deficiente por un 80% de pacientes en zonas rurales por la falta de personal capacitado y equipos

médicos en un estado inadecuado y la mitad de los encuestados rurales

tuvieron problemas con el idioma y las diferencias culturales [2].

Adicionalmente, la recomendación de la OMS es de 23 médicos por

cada 100 000 habitantes; mientras que zonas rurales de altura en

departamentos como Puno y Cajamarca sólo cuentan con 7.2 y 6.5

médicos por 100 000 habitantes, respectivamente [3]. Estos datos de

zonas rurales condicionan aún más el contexto de uso; resaltan la

necesidad de que el proyecto de solución pueda ser manejado

correctamente por personal no especializado, que se brinde una interfaz

con entrega de información y datos fáciles de entender, y que considere

las barreras de lenguaje presentes en la zona. Adicionalmente, la

solución debe considerar también los recursos limitados y posibles faltas

de electricidad estable y conectividad.

### 1.3. Usuario objetivo y necesidad clínica

- Usuario objetivo: Personal técnico de salud (técnicos en

enfermería) que realice la evaluación fisiológica inicial mediante

el triaje cardiopulmonar y personal de salud que se encuentre en

los puestos de salud de primer nivel.

- Necesidad clínica: Evaluar variables cardiopulmonares en

pacientes que acuden a puestos de salud de primer nivel en

zonas rurales de altura, con un sistema portátil operado por

personal de salud no especializado.

### 1.4. Problemática específica

Los puestos de salud de primer nivel en zonas rurales de altura carecen

de personal de salud especialista y de equipos médicos que evalúen

variables cardiopulmonares y tengan un ajuste según la altitud, lo que

resulta en clasificaciones erróneas y necesidad de traslados a otros

centros.

### 2. Sustento inicial de la problemática

### 2.1. Estadísticas relevantes

- Brecha de equipamiento e infraestructura: Al cierre de 2024, el 97% de

los establecimientos de salud del primer nivel de atención (postas y

centros de salud) en el Perú presentan una capacidad instalada

inadecuada, lo que implica deficiencias críticas tanto en infraestructura

como en equipamiento básico para el diagnóstico. [4]

- Subdiagnóstico en grandes alturas: En ciudades andinas situadas a más

de 3,000 msnm, el 65.3% de las personas que padecen hipertensión

arterial desconocen su diagnóstico, una cifra significativamente mayor

al promedio nacional, lo que evidencia la falta de monitoreo preventivo

en estas regiones. [5]

- Barreras de acceso geográfico: Más de 2 millones de peruanos que

viven en zonas rurales carecen de acceso a un diagnóstico de salud

oportuno; en muchos casos, los pacientes deben viajar hasta 3 días

para ser atendidos en un establecimiento con capacidad resolutiva. [6]

### 2.2. Justificación

La problemática es crítica en el Perú debido a la combinación de una geografía

accidentada y una infraestructura de salud centralizada. Mientras que las

enfermedades cardiovasculares son la principal causa de muerte en el país,

las poblaciones altoandinas enfrentan el desafío adicional de la hipoxia

hipobárica, la cual altera los signos vitales estándar (como la saturación de

oxígeno, que puede ser normal al 88% a 4,100 msnm). Un sistema de triaje

portátil y de bajo costo es relevante porque permite que el personal no

especialista en puestos de salud remotos (donde el 97% carece de equipos

adecuados) realice una clasificación precisa basada en algoritmos adaptados

a la fisiología de altura, evitando traslados innecesarios de varios días o

muertes por falta de detección temprana.

### 3. Análisis preliminar TRL y GAITS

### 3.1. Nivel TRL preliminar

Los niveles de madurez tecnológica (TRL) son métricas estandarizadas

para ubicar el nivel de madurez de desarrollo de una tecnología desde

la idea inicial hasta su validación e implementación empleando escalas del 1 al 9. No evalúa la necesidad clínica, sino qué tan desarrollada y

viable se encuentra la solución tecnológica.

Como parte de sus funciones, CONCYTEC ha diseñado escalas de

madurez tecnológica de 9 niveles.

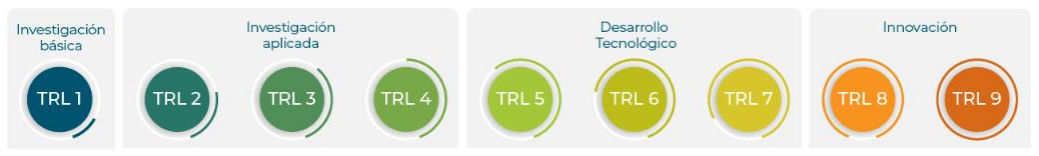
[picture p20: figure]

Figura 1. Niveles TRL

Fuente: Plataforma Vincúlate [7]

El proyecto se sitúa preliminarmente en el nivel TRL 2, ya que se

encuentra en una etapa de investigación aplicada donde se ha definido

una solución específica, el cual es un sistema de triaje cardiopulmonar

portátil para zonas rurales de altura. Aunque se han identificado los

componentes tecnológicos clave como la placa HealthyPi 5 y las

variables fisiológicas a medir (SpO2, FC y FR), la implementación sigue

siendo teórica y se fundamenta en la revisión del estado del arte

### 3.2. Análisis GAITS

GAITS (Guidance and Impact Tracking System) es una herramienta que

permite estructurar y evaluar proyectos de innovación en salud desde la

identificación de la necesidad de la población hasta la validación de la

solución, considerando el contexto completo.

El análisis de la problemática mediante la metodología GAITS revela

una necesidad en la dimensión clínica, donde el acceso limitado a

equipamiento biomédico en zonas rurales de altura dificulta la

evaluación fisiológica inicial en establecimientos de primer nivel, siendo

un entorno hostil donde se presentan cortes de energía constantes y

fallas eléctricas por el clima. Para abordar esta brecha, la dimensión

tecnológica propone el uso de la placa HealthyPi 5 de código abierto,

seleccionada por su capacidad para el monitoreo de signos vitales en

un formato portátil.

Desde las perspectivas regulatoria y de usabilidad, el proyecto se

fundamenta en el cumplimiento de normativas de seguridad eléctrica y

protocolos nacionales de salud, garantizando que sea un dispositivo

médico apto para ser operado por personal no especialista, asimismo,

el diseño se centrará en una interfaz de fácil interpretación en una

estructura capaz de soportar el transporte en zonas rurales aisladas.

### 4. Revisión breve de soluciones existentes

### 4.1. Análisis del estado del arte

[Solución 1]

Method of predicting acute cardiopulmonary events and

survivability of a patient

La patente mostrada propone un sistema portátil y wearable para el monitoreo continuo de señales fisiológicas, cuyo objetivo es la detección de eventos cardiopulmonares del paciente y, en base a la data obtenida, utilizar los algoritmos implementados en el sistema para estimar el riesgo del paciente y prevenir eventos críticos.[8]

[Solución 2]
Wearable Bluetooth Triage Healthcare Monitoring System

Presenta el diseño de un sistema portátil y wearable capaz de

monitorear de manera continua la función cardiaca y respiratoria del

paciente. Con este sistema, se logra sustituir múltiples equipos que

pueden faltar en zonas rurales y la información obtenida es fácil de

interpretar para el personal médico. [9]

[Solución 3]

VS 9 Vital Signs Monitor

El VS 9 es un monitor portátil de signos vitales que está diseñado para

entornos clínicos. Este monitor ofrece un monitoreo continuo de

diversos signos vitales, obteniendo información vital del paciente en poco tiempo, junto a ello, también incorpora un sistema automático de

Early Warning Score (EWS), el cual genera alertas de intervención

inmediata. [10]

[Solución 4]

Cardio Tag Sensor

El sensor Cardio Tag es un dispositivo wearable de monitoreo cardiaco

de manera no invasiva, el cual brinda información fácilmente

interpretable en tiempo real. Además, gracias a algoritmos de Deep

Learning, puede detectar posibles riesgos en el paciente antes que su

estado de salud empeore, consiguiendo una atención rápida y

especializada para cada paciente. [11]

### 4.2. Limitaciones de soluciones actuales

La mayoría de estas soluciones, a pesar de su excelente labor de

monitoreo y obtención de las variables biomédicas del paciente, no se

encuentran adaptados para zonas de altura, dejando a un lado

condiciones como la hipoxia hipobárica de altura, comúnmente presente

en comunidades de estas zonas; presentan una gran dependencia a la

conectividad de la zona y a alimentación de energía, generando

problemas en su funcionamiento por su bajo acceso en zonas de altura;

por último, éstos no cuentan con un triaje automatizado (sobre todo en

el contexto andino), limitándose a la detección de posibles riesgos en la

salud del paciente.

### 5. Cuadro comparativo de soluciones

Nombre de la solución | Función principal | Usuario objetivo | Señales o variables biomédicas | Ventajas | Limitaciones
Method of predicting acute | Monitoreo continuo y predicción | Paciente con riesgo cardiaco / | ECG, frecuencia cardiaca, | - Enfoque predictivo | - Dependencia de batería y tecnología

cardiopulmo nary events and survivability of a patient | de eventos cardiopulmo nares | médicos | variabilidad de la frecuencia cardiaca (HRV) | - Portátil (wearable) - Detecta deterioro temprano | - No adaptado a zonas de altura - No realiza triaje
Wearable Bluetooth Triage Healthcare Monitoring System | Monitoreo portátil de funciones cardiopulmo nares | Personal clínico / pacientes con riesgo cardiaco | ECG, SpO2 frecuencia respiratoria | - Monitoreo en tiempo real - Diseño portátil y wearable - Integra múltiples sensores | - Experimental - Requiere conectividad - No adaptado a contexto rural
VS 9 Vital Signs Monitor | Monitoreo de signos vitales y detección de deterioro (EWS) | Personal médico | Presión arterial, SpO2, frecuencia respiratoria, temperatura corporal | - Mide múltiples signos vitales clínicos - Alta precisión - Uso de EWS (detección de deterioro automático) | - Dependencia de personal calificado - Poco adaptable a zonas rurales - Uso obligatorio de energía eléctrica
Cardio Tag Sensor | Monitoreo avanzado y predicción mediante IA | Pacientes con riesgo cardiaco | ECG, PPG y SCG | - Análisis profundo del corazón - Uso de IA para una detección temprana - Monitoreo continuo fuera del hospital | - Triaje incompleto - No está adaptado para zonas de altura - Alta dependencia tecnológica

### 6. Validación inicial con Stakeholders

### 6.1. Entrevistado [Médico General y Patólogo: Dr. Ladmila Ruiz Guio]

Perfil del entrevistado: Médico General adscrita al área de Patología del

Hospital Regional "Víctor Ramos Guardia" (Huaraz). Posee amplia

experiencia en el abordaje de afecciones respiratorias severas adquirida durante la pandemia de COVID-19 y un profundo conocimiento de la

realidad clínica, logística y de triaje en el primer nivel de atención de

zonas altoandinas, habiendo ejercido en el distrito de Cátac y la ciudad

de Huaraz. CMP N° 018505

6.1.1. Preguntas realizadas:
- ¿Qué problemas nota al medir la saturación de oxígeno en

pacientes debido a la altura?

- ¿Cómo afectan los cortes de luz al uso de sus equipos médicos

actuales?

- ¿Qué tan difícil resulta interpretar los datos de los monitores

sin un médico especialista al lado?

- ¿Con qué frecuencia sus equipos fallan o se descargan por el

clima frío de la zona?

- ¿Qué información le ayudaría más a decidir si un paciente

realmente necesita un traslado a otro hospital?

### 6.2. Principales hallazgos (Resumen)

- Falta de adaptación fisiológica: Se validó que los equipos

estándar generan confusión (falsos positivos) al no estar

calibrados para la hipoxia hipobárica de altura, marcando niveles

de SpO2 como anormales cuando son habituales en la región.

- Brecha de usabilidad: El personal técnico carece de la formación

especializada para interpretar múltiples variables aisladas , lo

que confirma la necesidad de un sistema que integre los datos y

ofrezca un algoritmo de riesgo automatizado (triaje).

- Vulnerabilidad tecnológica: La inestabilidad de la red eléctrica en

zonas rurales e incluso los apagones en la ciudad de Huaraz

vuelve obsoletos los equipos hospitalarios tradicionales, por su

puesto que hay una fuente de energía de reserva en el hospital,

pero en el caso de las postas médicas y hospitales de nivel I la

situación no es la misma y es aún más crítica. Es fundamental

que el dispositivo a desarrollar tenga alta autonomía energética

y no dependa de conexión a internet para procesar los datos.

7. | Reformulación | del | problema
| Integración de hallazgos:

La evidencia recopilada expone una vulnerabilidad crítica en el sector salud ,

ya que existe una brecha del 97% de equipamiento biomédico en

establecimientos de primer nivel y barreras geográficas que obligan a traslados

de hasta 3 días. La revisión del estado del arte y las consultas con stakeholders

confirman que las soluciones actuales omiten el ajuste por hipoxia hipobárica,

donde una saturación de 88-92% es fisiológicamente normal. Estos hallazgos

validan la necesidad de un sistema portátil que automatice el triaje y asista al

personal no especialista en la toma de decisiones clínicas en campo

Reformulación de la problemática clínica y tecnológica:

El personal rural realiza triajes inexactos por la carencia de dispositivos que

integren señales de ECG, PPG y Respiración calibradas para la altitud, lo cual

impide una clasificación de riesgo efectiva y deriva en traslados innecesarios o

mortalidad evitable por falta de diagnósticos oportunos.

Principal brecha tecnológica detectada:

Inexistencia de una plataforma biomédica portátil con capacidad de adquisición

multiseñal y procesamiento local de algoritmos de soporte a la decisión clínica,

diseñados específicamente bajo los parámetros de la fisiología del residente

altoandino.

### 8. Bibliografía

[1] A. Tinoco-Solórzano et al., “Definitions and consensus recommendations on critical care medicine at altitude from the Expert Committee on Critical Care Medicine at altitude of the Pan-American and Iberian Federation of Critical Care Medicine and Intensive Care,” Medicina Intensiva, vol. 49, 2025, Art. no. 502256.
[2] L. D. Muchari Candia, “Inequalities in Access to Health Services in Peru: Analysis of the Gaps between Rural and Urban Areas,” World Health Journal, vol. 5, no. 2, pp. 18–21, Dec. 2024.
[3] Defensoría del Pueblo, “Informe Defensorial N.° 243: Supervisión a los Institutos Especializados de Salud de Lima y Regiones,” Lima, Perú, Apr. 2025.
[4] ComexPerú, “Avance del cierre de brechas en infraestructura del sector salud,” Dic. 2024. [En línea]. Disponible: https://www.comexperu.org.pe/articulo/avance-del-cierre-de-brechas-en-infraestructura-del-sector-salud. (https://www.comexperu.org.pe/articulo/avance-del-cierre-de-brechas-en-infraestructura-del-sector-salud)
[5] L. Segura et al., “Factores de riesgo de las enfermedades cardiovasculares en el Perú (Estudio TORNASOL),” Rev. Peru. Cardiol., vol. 32, no. 2, pp. 82-120, 2006.
[6] A. Espinoza, “Más de 2 millones de peruanos viven sin acceso a un diagnóstico de salud: en zonas rurales, viajan hasta 3 días para ser atendidos,” Infobae, Jun. 2025
[7] | Plataforma | VINCÚLATE, | “Paquete | tecnológico | y | valorización,”
Vinculate.concytec.gob.pe. | [En | línea]. | Disponible | en:
https://vinculate.concytec.gob.pe/paquete-tecnologico-y-valorizacion/. [Accedido: 02-abr-2026].

[8] M. E. H. Ong, Z. Lin, W. Ser, and G. Huang, “US20130237776A1 - Method
of predicting acute cardiopulmonary events and survivability of a patient | -
Google | Patents,” | Mar. | 15, | 2010.
https://patents.google.com/patent/US20130237776A1/en
[9] | Mdpi.com. | [Online]. | Available: | https://www.mdpi.com/1424-
8220/21/22/7586. [Accessed: 04-Apr-2026].
[10] “VS 9 vital sign monitor for hospitals : Best Vital Signs Monitor by Mindray,”
Mindray.com. | [Online]. | Available:
https://www.mindray.com/na/products/patient-monitoring/vital-signs-monitors/vs-9/. [Accessed: 04-Apr-2026].
[11] “The next frontier in cardiac disease management,” Cardiosense, 29-July-2025. [Online]. Available: https://cardiosense.com/. [Accessed: 04-Apr-2026].

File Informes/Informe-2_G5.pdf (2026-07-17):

## UNIVERSIDAD PERUANA CAYETANO HEREDIA

### INGENIERÍA BIOMÉDICA

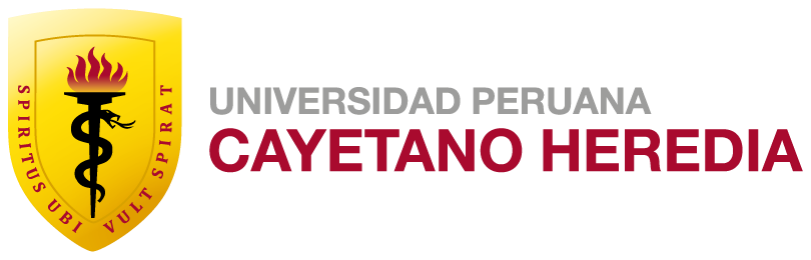
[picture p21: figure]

# PRÁCTICA DE INSTRUMENTACIÓN BIOMÉDICA

## Presentación de la Problemática Tecnológica, desarrollo de la idea de solución, y la lista de exigencias

## [Práctica N°2]

GRUPO N°: 5
Nombre de los Integrantes y código:
- Aldo David Manturano Lopez - 72387388
- David Eddy Aguilar Yahuana - 71421807
- Juan Raul Ramirez Mendoza - 72642526
- Alejandra Ivonne Gamarra Leyva - 72771921
- Davidt Brayamn Fernandez Bernaola - 72165022
- Gustavo Andre Ruiz Ortiz - 72899306

2026 -1

### 1. Reformulación del problema tecnológico

Variables fisiológicas de interés : Nos enfocaremos en tres indicadores vitales para el triaje: la saturación de oxígeno (SpO2), que nos dice qué porcentaje de la sangre lleva oxígeno; la frecuencia cardíaca, para monitorear el ritmo del corazón; y la frecuencia respiratoria, que es el primer signo de alerta ante una neumonía o mal de altura.

Método de adquisición propuesto: Utilizaremos métodos no invasivos, lo que significa que no causan dolor ni requieren muestras de sangre: 1.Fotopletismografía (PPG): Usaremos el sensor de clip del kit HealthyPi 5. Este emite luces (roja e infrarroja) a través del dedo; la cantidad de luz que la sangre absorbe nos permite calcular matemáticamente el nivel de oxígeno. 2.Biopotenciales de superficie: Colocaremos tres electrodos en el tórax del paciente. Estos parches captan los impulsos eléctricos del corazón para formar el electrocardiograma (ECG) y, al mismo tiempo, detectan los cambios eléctricos causados por el movimiento de los pulmones al respirar.

Contexto de uso : El sistema operará en puestos de salud rurales de altura (más de 3,500 msnm). Son entornos críticos donde el aire tiene menos presión de oxígeno (hipoxia hipobárica), la electricidad falla constantemente y el personal encargado suele ser técnico, no especialista en cardiología.

Principal brecha tecnológica detectada: Existe una desconexión entre la ingeniería de los equipos comerciales y la realidad de los Andes. Los dispositivos actuales están programados para el nivel del mar; por eso, si ven a alguien con 88% de oxígeno, activan alarmas de emergencia, sin conocer que para un poblador de altura ese valor es fisiológicamente normal.

Oportunidad concreta de desarrollo: Nuestra oportunidad es usar el procesador RP2040 de la placa Healthy Pi 5 para codificar un sistema personalizado con elevadas alturas. Programaremos algoritmos que ajusten automáticamente los rangos de normalidad según la altura, permitiendo que el equipo clasifique al paciente de forma correcta y entregue un resultado fácil de entender, como un semáforo de riesgo.

### 2. Decisión técnica basada en Healthy Pi 5

2.1. Señales del Healthy Pi 5
La plataforma Healthy Pi 5 integra dos chips especializados que permiten adquirir múltiples señales fisiológicas de forma simultánea y sin hardware externo adicional. A continuación se describen las señales primarias y la señal derivada que serán utilizadas en el sistema de triaje.
2.1.1. Señales primarias
2.1.1.1. Electrocardiograma (ECG)
El ECG es adquirido por el chip MAX30001 el cual es un AFE (Analog Front End) que detecta las diferencias de potencial eléctrico generadas por la despolarización y repolarización del músculo cardíaco a través de electrodos de superficie colocados en el tórax del paciente.
2.1.1.2. Oximetría de pulso (SpO2) La señal de SpO2 es capturada mediante un sensor óptico externo y procesada por el chip AFE4400, que actúa como el Front-End Analógico (AFE) del sistema, permitiendo convertir los datos analógicos en datos digitales precisos, permitiendo así el cálculo de la saturación de oxígeno por parte del procesador central [1]
2.1.2. Señal derivada
2.1.2.1. Frecuencia respiratoria (FR) La Frecuencia Respiratoria (FR) se obtiene como señal derivada del ECG mediante la técnica de Neumografía por Impedancia Transtorácica. Esta técnica no requiere sensores adicionales: utiliza los mismos tres electrodos del ECG para medir los cambios en la impedancia eléctrica del tórax provocados por el ciclo respiratorio.
2.2. Rutas técnicas
2.2.1. Ruta técnica de visualización en laboratorio Esta ruta se activa durante la fase de desarrollo, calibración y validación del algoritmo de triaje, el objetivo es brindar acceso completo a las señales crudas para ajustar parámetros y verificar la calidad de la señal. Componentes de la ruta:
I. Adquisición de señales
II. | Transmisión de señales (USB)
III. | Visualización OpenView

IV. Procesamiento y validación por Python
V. Almacenamiento en PC
La conexión a PC con OpenView garantiza que cualquier artefacto o ruido en la señal sea detectado y corregido antes del despliegue en campo.
2.2.2. Ruta técnica de visualización en producto final Esta ruta corresponde al sistema desplegado en el puesto de salud rural, este diseño elimina toda dependencia de infraestructura externa con el objetivo de presentar autonomía en zonas remotas y simplicidad operativa en el triaje del paciente. Componentes de la ruta:
I. Adquisición de señales
II. | Procesamiento embebido
III. | Visualización en pantalla TFT
IV. | Registro local MicroSD
V. Post-procesamiento MicroSD
El procesamiento embebido en la placa y la visualización en pantalla TFT elimina la dependencia de un PC o conexión a internet, esto garantiza que el equipo sea portátil y operativo en cualquier puesto de salud de primer nivel.

### 3. Revisión tecnológica focalizada 3.1. Solución 1

ERTRIAGE DH-600

Es una estación médica inteligente cuya función es la recopilación inmediata de los signos vitales del paciente (presión, SpO2, ECG, temperatura) y, tomando en cuenta esta información, los síntomas y la historia médica del paciente, clasifica al paciente en base a la gravedad de su condición en menos de 3 minutos, mediante el uso de un sistema de IA integrado de modelos de Machine Learning y programación nativa de Android. [2]

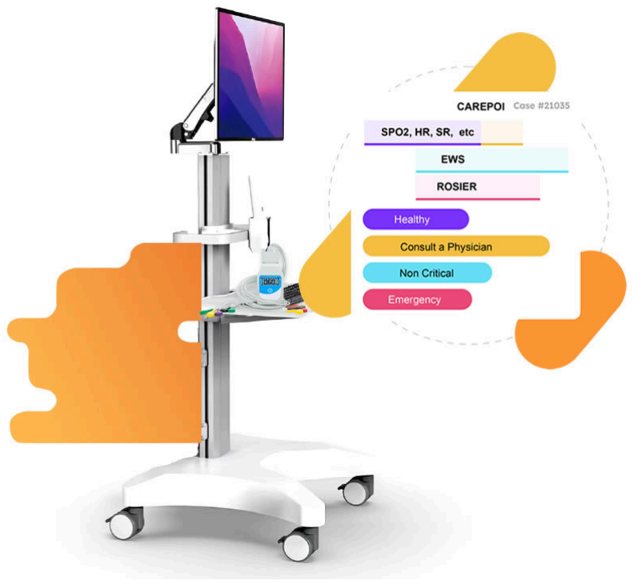
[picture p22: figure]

### 3.2. Solución 2

Systems and methods for automated triage and scheduling in an emergency department

Esta patente propone un sistema de triaje, programación y/o monitoreo del paciente, en donde se obtiene la información del paciente usando un dispositivo de evaluación del paciente y se monitorea sus signos vitales y síntomas usando, por ejemplo un brazalete. Con la información recolectada, un sistema computarizado la analizará y asignará al paciente un nivel de riesgo, según su condición. Además, esta información puede ser almacenada en un historial médico del paciente para futuras observaciones. [3]

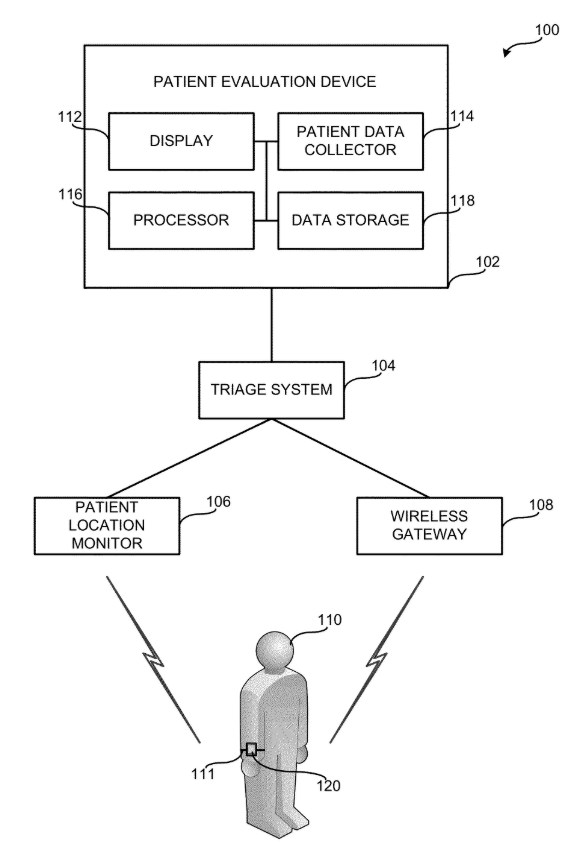
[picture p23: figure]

### 3.3. Solución 3

Smart Triage Tag – intelligent emergency wristband

Es una pulsera inteligente que mide y monitorea los signos vitales de varios pacientes de manera simultánea, usa tecnología IoT para enviar esta información a una aplicación de Android, cuyo objetivo es el monitoreo continuo. Además, puede clasificar a los pacientes mediante colores según su nivel de riesgo y puede actualizar esta clasificación cuando detecte la deterioración de su salud.[4]

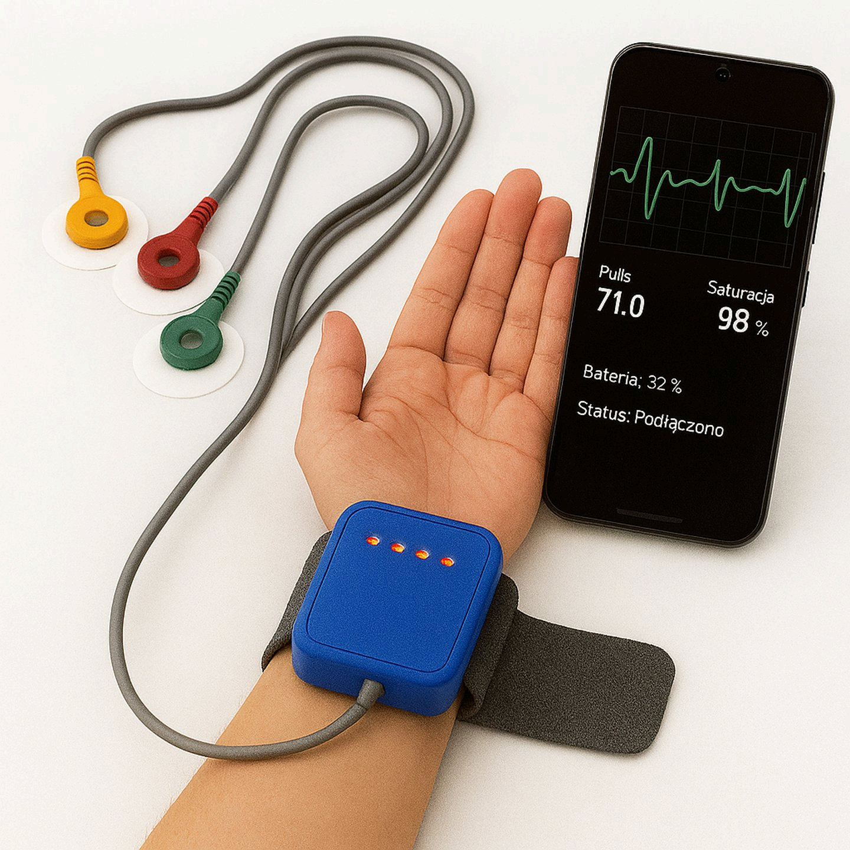
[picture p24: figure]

### 3.4. Solución 4

Masimo Rad-G® (Masimo)
Oxímetro de pulso portátil de alta resistencia, reconocido por su fiabilidad en condiciones extremas de movimiento y baja perfusión.Utiliza la tecnología Signal Extraction Technology (SET®), la cual filtra el ruido causado por el frío o el movimiento del paciente, asegurando una lectura de SpO2 exacta [5].


### 3.5. Solución 5

Smart Triage Algorithm (BC Children's Hospital)
Sistema de salud digital diseñado para el triaje predictivo en entornos con recursos limitados, como zonas rurales o países en desarrollo.Se basa en modelos matemáticos de predicción clínica instalados en dispositivos móviles que guían al personal de salud paso a paso.Proporciona la base metodológica para nuestro software. Valida que el triaje asistido por algoritmos reduce la mortalidad en lugares donde no hay médicos especialistas [6].


Cuadro comparativo de las referencias mencionadas

Solución | Variable medida | Tecnología utilizada | Ventaja principal | Limitación principal
ERTRIAGE DH-600 | ECG, Presión arterial, SpO2, FC y Temperatura | Monitor de grado clínico con sistema de alerta temprana (EWS) | Alta precisión clínica y generación automática de alertas de riesgo | Alta dependencia de energía eléctrica y difícil transporte en zonas rurales
Systems and methods for automated triage and scheduling in an emergency department | Presión arterial, SpO2 y FC | Algoritmos de Deep Learning para análisis cardiaco continuo | Permite detectar riesgos cardíacos antes de que el paciente presente síntomas | No está calibrado para condiciones de altitud y requiere alta conectividad
Smart Triage Tag – intelligent emergency wristband | FC, SpO2 y ECG | Tecnología IoT conectada a una aplicación móvil mediante Bluetooth | Permite monitorear a varios pacientes a la vez con clasificación por colores | Dependencia crítica de un smartphone externo y de una conexión estable
Masimo Rad-G® (Masimo) | SpO2, Frecuencia Cardíaca y FR | Tecnología SET® para filtrado de ruido por movimiento y frío | Excelente desempeño en condiciones de baja perfusión (manos frías), comunes en altura | Costo de adquisición elevado y no cuenta con ECG para un triaje cardiaco integral
Smart Triage Algorithm (BC Children's Hospital) | Variables fisiológicas integradas | Algoritmos de soporte a la decisión clínica para entornos de bajos recursos | Automatiza la clasificación de urgencia, reduciendo el error del personal no especialista | Los umbrales de alerta están diseñados para nivel del mar, requiriendo ajuste para altura

### 4. Validación inicial de la idea de solución

La validación inicial se centra en demostrar que la arquitectura basada en el procesador RP2040 y los front-ends analógicos de la HealthyPi 5 es capaz de resolver el problema de triaje en entornos de altura crítica.

### 4.1. Viabilidad Técnica de la Adquisición

Se confirma que la plataforma integra circuitos de grado clínico que permiten una adquisición de señales robusta [1]:

Monitoreo Cardiorrespiratorio: El chip MAX30001 permite obtener el ECG y la Frecuencia Respiratoria (FR) por impedancia transtorácica simultáneamente, eliminando la necesidad de sensores externos de respiración [2][13].

Oximetría de Precisión: La inclusión del chip AFE4400 asegura una conversión digital de alta resolución para la SpO2, fundamental para compensar la baja perfusión periférica en climas fríos [2][15].

Procesamiento Embebido: El uso del microcontrolador RP2040 facilita el procesamiento local de señales sin depender de conectividad constante, permitiendo la implementación de algoritmos de filtrado y detección de picos en tiempo real [14].

### 4.2. Validación de la Adaptación Fisiológica (Algoritmo de Altura)

El núcleo de la innovación radica en la reprogramación de los umbrales de alerta:

Ajuste de Umbrales: A diferencia de los equipos comerciales calibrados para el nivel del mar que activan alarmas a menos de 90% de SpO2, nuestro sistema valida valores de 85-88% como normales para poblaciones residentes a más de 3,500 msnm [2][13].

Clasificación de Riesgo: La validación algorítmica se basa en la correlación entre la SpO2 y la FR para evitar falsos positivos de emergencia, utilizando un sistema de visualización tipo "semáforo" intuitivo para personal no especialista [2][11].

### 4.3. Validación Normativa y de Seguridad

El diseño se ha validado frente a los estándares internacionales para entornos no controlados:

Seguridad Eléctrica: El cumplimiento de la norma IEC 60601-1-11 asegura que el dispositivo es seguro en hogares o postas sin conexión a tierra confiable, gracias a su alimentación por baterías y aislamiento de Clase II [5][8].

Factor de Corrección por Altitud: Siguiendo la norma IEC 60601-1, se valida que el diseño de la PCB debe incrementar las distancias de aislamiento en un factor de 1.48 para operar de forma segura a 5,000 metros de altura [7][9].

Protección de Datos: La implementación de almacenamiento cifrado en MicroSD responde a las exigencias de la Ley N° 29733, garantizando la privacidad de los datos sensibles en zonas rurales [6][12].

### 5. Normativas y restricciones de diseño

### 1. Seguridad eléctrica en entornos de salud no controlados: IEC 60601-1-11

Debido a que el dispositivo será operado en puestos de salud rurales y hogares con infraestructura eléctrica impredecible, la norma IEC 60601-1-11 es la restricción técnica más relevante. Esta norma establece los requisitos de seguridad para equipos médicos utilizados en entornos donde no siempre hay un profesional de la salud presente o donde la instalación eléctrica carece de una conexión a tierra confiable [8].

Impacto en el diseño del sistema:

Aislamiento de Clase II: Dado que muchas viviendas y centros de salud en zonas rurales altoandinas no tienen una puesta a tierra adecuada, el dispositivo debe ser diseñado como Clase II (doble aislamiento) o contar con alimentación interna por baterías de litio. Esto elimina la dependencia de la infraestructura del edificio para prevenir descargas eléctricas [5].

Factor de corrección por altitud: La norma general IEC 60601-1 exige aumentar las distancias de aislamiento de aire (clearance) para compensar la baja presión barométrica en altitudes superiores a los 2000 metros. Para operar de forma segura a 5000 metros de altura (como en Puno o Pasco), el diseño de la placa electrónica (PCB) debe incrementar estas distancias en un factor de 1,48 para evitar la formación de arcos eléctricos debido al aire menos denso [6][10].

Robustez mecánica: La norma exige que el equipo portátil soporte condiciones de uso rudo. El chasis debe resistir caídas de hasta 1 metro de altura sobre superficies duras y poseer un grado de protección mínimo de IP22 contra el ingreso de partículas y humedad [8].

### 2. Almacenamiento y privacidad de datos: Ley N° 29733

Dado que el sistema captura variables fisiológicas como el Electrocardiograma (ECG) y la saturación de oxígeno (SpO2), estos datos son catalogados como "datos sensibles" bajo la Ley N° 29733 (Ley de Protección de Datos Personales) del Perú. El software debe garantizar la confidencialidad e integridad de esta información clínica [7].

Impacto en el diseño del sistema:

Consentimiento informado por diseño: La interfaz de usuario debe incluir un módulo para registrar el consentimiento previo, informado y expreso del paciente antes de la recolección de datos. Para datos de salud, la ley peruana requiere que este consentimiento sea otorgado por escrito, lo cual se traduce en una firma digital capturada en el dispositivo o una validación biométrica vinculada a la identidad del usuario [11].

Cifrado y Anonimización: Debido a la falta de conectividad constante en zonas rurales, el dispositivo debe utilizar almacenamiento local seguro. El software debe implementar algoritmos de cifrado como AES-256 para los archivos locales (JSON/CSV) y permitir la anonimización o disociación de los datos antes de ser exportados para vigilancia epidemiológica regional, asegurando que la identidad del paciente sea irreversiblemente separada de su clínica [12].

### 6. Lista de exigencias

Fecha | Deseo o exigencia | Descripción | Responsable
08/04/26 | E | Función principal: Adquirir, procesar, visualizar y almacenar señales de ECG, SpO2 y frecuencia respiratoria para triaje cardiopulmonar en tiempo real. | Todos
08/04/26 | E | Usuario objetivo: Personal técnico de salud (técnicos en enfermería) que realice la evaluación fisiológica inicial mediante el triaje cardiopulmonar y personal de salud variado que se encuentre en los puestos de salud de primer nivel. | Todos
08/04/26 | E | Contexto de uso: Uso hospitalario, el sistema va a funcionar en puestos de salud de primer nivel rurales y de altura, considerando recursos limitados, posibles fallas en la electricidad, barreras de lenguaje y falta de personal especializado. | Todos
08/04/26 | E | Señal a medir: Entrada: Biopotenciales de superficie captados mediante electrodos, señales de fotopletismografía (PPG) mediante un sensor. Salida: Señal ECG visualizable, frecuencia cardíaca estimada, saturación de oxígeno, frecuencia respiratoria como señal derivada del ECG y registro de datos. | Brayamn, David
08/04/26 | E | Precisión esperada: Las señales adquiridas deberán tener una calidad suficiente y un buen manejo del ruido para estimar las variables de frecuencia cardíaca, frecuencia respiratoria y saturación de oxígeno de manera confiable. | Alejandra, Aldo
08/04/26 | E | Portabilidad: El sistema debe ser liviano, de uso portátil y fácil de transportar de forma segura, considerando que deberá ser enviado a zonas alejadas del país. | Gustavo
08/04/26 | E | Energía: El sistema deberá funcionar mediante alimentación interna por baterías recargables. | David, Juan
08/04/26 | D | Autonomía: La batería deberá permitir el uso del sistema de triaje para 50 pacientes antes de necesitar una recarga. | Alejandra
08/04/26 | E | Electrónica: El sistema usará la plataforma Healthy Pi 5, el MAX30001 Y el AFE4400 para la adquisición de las señales. | Gustavo, Alejandra

08/04/26 | E | Seguridad: El sistema deberá trabajar de acuerdo a la normativa de seguridad eléctrica IEC 60601-1-11, con niveles seguros de alimentación y un factor de corrección adecuado para evitar riesgo eléctrico [5][6][8]. | Aldo, Juan
08/04/26 | D | Ergonomía: El uso del sistema en el usuario, la colocación de los electrodos y la interfaz de entrega de resultados deberán ser intuitivos y cómodos para el usuario. | Alejandra
08/04/26 | E | Robustez mecánica: Los componentes del sistema deberán soportar caídas sobre superficies duras y las condiciones propias de zonas de altura como bajas temperaturas. | Aldo, Brayamn
08/04/26 | D | Costo: El diseño deberá considerar principalmente componentes accesibles y priorizar un sistema de bajo costo. | Juan
08/04/26 | E | Fabricación: La integración, ensamblaje y mantenimiento de los componentes del sistema deberán estar acordes a la experiencia y habilidades de los miembros del grupo. | Todos
08/04/26 | E | Almacenamiento: El sistema podrá guardar los registros de las señales en una tarjeta MicroSD. | Juan
08/04/26 | E | Visualización: El sistema deberá permitir la visualización clara de las señales procesadas en una pantalla TFT. | Brayamn
08/04/26 | E | Clasificación: El sistema dará una clasificación del paciente según su nivel de riesgo, acorde a las señales medidas y de fácil interpretación para facilitar la entrega de resultados y posible derivación. | David, Gustavo
08/04/26 | E | Conectividad: Los datos del sistema se podrán transmitir mediante una tarjeta MicroSD. | Brayamn

### 7. Primer boceto de la solución


- Descripción del Boceto Conceptual de la Solución: El diseño propuesto materializa una unidad de triaje portátil y robusta, diseñada específicamente para operar en entornos rurales. La arquitectura del dispositivo se fundamenta en la plataforma HealthyPi 5, integrando el microcontrolador central con los chips de grado clínico MAX30001 (para la adquisición de ECG y frecuencia respiratoria por impedancia) y el AFE4400 (para la oximetría de pulso de alta precisión).Características destacadas del diseño:Interfaz de Usuario Simplificada: Se implementa una perilla de control multifunción (giratoria y pulsador) que reduce la complejidad operativa, permitiendo al personal técnico navegar menús y registrar pacientes de manera eficiente en condiciones de campo.Sistema de Clasificación Visual: El dispositivo cuenta con un panel LED único que actúa como semáforo de riesgo, cambiando de color (rojo, amarillo o verde) según el algoritmo de triaje embebido.Algoritmo Ajustado por Altitud: A diferencia de los equipos convencionales, este sistema procesa los valores de SpO2 y frecuencia respiratoria considerando la hipoxia hipobárica de zonas superiores a los 3,500 msnm, evitando falsas alarmas y validando niveles de saturación fisiológicamente normales para residentes de altura.Seguridad y Privacidad de Datos: El chasis incluye una ranura para tarjeta MicroSD, donde se almacenan los registros clínicos de forma cifrada, garantizando el cumplimiento de la Ley N° 29733 de Protección de Datos Personales del Perú.Autonomía y Robustez: El sistema es alimentado por una batería interna de Li-Ion de alta duración, cumpliendo con la normativa IEC 60601-1-11 para su uso seguro en entornos sin una infraestructura eléctrica estable.

### 8. Bibliografía

[1] Crowd Supply, “HealthyPi 5: The world’s first open-source clinical-grade vitals monitor,” Crowd Supply, [En línea]. Disponible en: https://www.crowdsupply.com/protocentral/healthypi-5. [Accedido: 22-may-2024].
[2] ErtriageTM DH-600 (2025) The world’s first device-based AI triage system. Disponible en: https://ertriage.com/ertriage-dh-600/ [Accedido: 09-april-2026].
[3] US20130030825A1 - systems and methods for automated triage and scheduling in an emergency department (sin fecha) Google Patents. Disponible en: https://patents.google.com/patent/US20130030825A1/en (Accedido: 09-april-2026).
[4] Smart triage tag (2025) – intelligent emergency wristband | James Dyson Award.
Disponible en:
https://www.jamesdysonaward.org/2025/project/smart-triage-tag-intelligent-emergenc y-wristband (Accedido: 09-april-2026).
[5] Medical electrical equipment - Part 1-11: General requirements for basic safety and essential performance - Collateral Standard: Requirements for medical electrical equipment and medical electrical systems used in the home healthcare environment, IEC 60601-1-11:2015, 2015.
[6] Congreso de la República del Perú, Ley de Protección de Datos Personales, Ley N° 29733, 2011.
[7] Medical electrical equipment - Part 1: General requirements for basic safety and essential performance, IEC 60601-1:2005+AMD1:2012, 2012.
[8] Advanced Energy, "Safety standards for home healthcare devices," 2024. [En línea]. Disponible en: https://www.advancedenergy.com/en-us/about/news/blog/safety-standards-for-home-healthcare-devices/ (https://www.advancedenergy.com/en-us/about/news/blog/safety-standards-for-home-healthcare-devices/)
[9] Medical Adapter Tech, "Altitude derating and insulation requirements for power supply design," 2024. [En línea]. Disponible en: https://medicaladaptertech.com/medical-industry-news/altitude-derating-insulation-requirements-power-supply-design/ (https://medicaladaptertech.com/medical-industry-news/altitude-derating-insulation-requirements-power-supply-design/)
[10] Starfish Medical, "Addressing ingress protection for home healthcare medical devices," 2022. [En línea]. Disponible en: https://starfishmedical.com/resource/addressing-ingress-protection-for-home-healthcare-medical-devices/ (https://starfishmedical.com/resource/addressing-ingress-protection-for-home-healthcare-medical-devices/)
[11] Ministerio de Salud del Perú (MINSA), "Ley de Protección de Datos Personales y su impacto en salud," 2023. [En línea]. Disponible en: https://www.minsa.gob.pe/Recursos/OGTI/SINADEF/Ley-29733.pdf
[12] Defensoría del Pueblo, "Manual de Protección de Datos Personales,"

Lima, Perú, 2019. [En línea]. Disponible en: https://www.defensoria.gob.pe/wp-content/uploads/2019/11/Manual-de-Protec ci%C3%B3n-de-Datos-Personales.pdf (https://www.defensoria.gob.pe/wp-content/uploads/2019/11/Manual-de-Protecci%C3%B3n-de-Datos-Personales.pdf)

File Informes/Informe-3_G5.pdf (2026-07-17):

## UNIVERSIDAD PERUANA CAYETANO HEREDIA

### INGENIERÍA BIOMÉDICA


## PRÁCTICA DE INSTRUMENTACIÓN BIOMÉDICA

## Presentación de Caja Negra, Estructura de Funciones, Alternativas de Solución (VDI 2221) y Solución Escogida

## [Práctica N°3]

GRUPO N°: 5
Nombre de los Integrantes y código:
- Aldo David, Manturano Lopez - 72387388
- David Eddy, Aguilar Yahuana - 71421807
- Juan Raul, Ramirez Mendoza - 72642526
- Alejandra Ivonne, Gamarra Leyva - 72771921
- Davidt Brayamn, Fernandez Bernaola - 72165022
- Gustavo Andre, Ruiz Ortiz - 72899306

2026 -1

### 1. Integracion de resultados

Problema clínico definido: Existe una brecha tecnológica en los puestos de salud rurales de altura, en los cuales los equipos convencionales no consideran las diferencias en la saturación de oxígeno (Spo2) debido a los niveles de altura. Esto sucede debido a que operan bajo estándares de nivel del mar, por lo que ignoran que en la altura la presión de oxígeno es menor (hipoxia hipobárica).

Variables fisiológicas seleccionadas: Monitoreamos la saturación de oxígeno, frecuencia respiratoria y frecuencia cardiaca.

Señales biomédicas identificadas: El dispositivo captará señales de fotopletismografía (PPG) para el cálculo de oxígeno y pulso. Además se usarán señales de biopotenciales eléctricos (ECG) para la actividad del corazón y la respiración.

Sensores y módulos (chips) seleccionados: Usaremos el kit completo de Healthy Pi 5:
- AFE4400: Estará encargado de procesar la señal óptica del sensor del clip del dedo (SpO2).
- MAX30001: Se encargará de la recolección de ECG y la obtención la obtención de la frecuencia respiratoria mediante la técnica de impedancia torácica [1]

Flujo general de señal: Nuestra señal biológica será captada por los electrodos y el clip del dedo, acondicionada y digitalizada por los chips AFE (AFE4400 y MAX30001). Luego, el RP2040 va a procesar estos datos y aplicará los modelos matemáticos de transformaciones de valores según la altitud configurada. Finalmente, la información se podrá visualizar mediante una pantalla TFT y se guardará en la tarjeta Micro SD para la auditoría médica

### 2. Lista de exigencias

Fecha | Deseo o exigencia | Descripción | Responsable
08/04/26 | E | Función principal: Adquirir, procesar, visualizar y almacenar señales de ECG, SpO2 y frecuencia | Todos

| | respiratoria para triaje cardiopulmonar en tiempo real.
08/04/26 | E | Usuario objetivo: Personal técnico de salud (técnicos en enfermería) que realice la evaluación fisiológica inicial mediante el triaje cardiopulmonar y personal de salud variado que se encuentre en los puestos de salud de primer nivel. | Todos
08/04/26 | E | Contexto de uso: Uso hospitalario, el sistema va a funcionar en puestos de salud de primer nivel rurales y de altura, considerando recursos limitados, posibles fallas en la electricidad, barreras de lenguaje y falta de personal especializado. | Todos
08/04/26 | E | Señal a medir: Entrada: Biopotenciales de superficie captados mediante electrodos, señales de fotopletismografía (PPG) mediante un sensor. Salida: Señal ECG visualizable, frecuencia cardíaca estimada, saturación de oxígeno, frecuencia respiratoria como señal derivada del ECG y registro de datos. | Brayamn, David
08/04/26 | E | Precisión esperada: Las señales adquiridas deberán tener una calidad suficiente y un buen manejo del ruido para estimar las variables de frecuencia cardíaca, frecuencia respiratoria y saturación de oxígeno de manera confiable. El sistema deberá estimar la frecuencia cardíaca con un error máximo de ± 3 bpm; la frecuencia respiratoria con ± 2 rpm y el SpO2 con un error máximo de ± 2%. | Alejandra, Aldo
08/04/26 | E | Portabilidad: El sistema debe ser liviano, de uso portátil y fácil de transportar de forma segura, considerando que deberá ser enviado a zonas alejadas del país. | Gustavo
08/04/26 | E | Energía: El sistema deberá funcionar mediante alimentación interna por baterías recargables. | David, Juan
08/04/26 | D | Autonomía: La batería deberá permitir el uso del sistema de triaje para 50 pacientes antes de necesitar una recarga. | Alejandra
08/04/26 | E | Electrónica: El sistema usará la plataforma Healthy Pi 5, el MAX30001 Y el AFE4400 para la adquisición de las señales. | Gustavo, Alejandra
08/04/26 | E | Seguridad: El sistema deberá trabajar de acuerdo a la normativa de seguridad eléctrica IEC 60601-1-11, con niveles seguros de alimentación y un factor de corrección adecuado para evitar riesgo eléctrico. Además, los componentes del sistema deberán soportar caídas sobre superficies duras y | Aldo, Juan

### 3. Arquitectura Funcional del Sistema

3.1. Diagrama de Caja Negra


### 1. Entradas (Inputs)

Señales Fisiológicas: Biopotenciales eléctricos captados del tórax y variaciones de intensidad lumínica captadas en tejido periférico.
Energía: Fuente de alimentación eléctrica continua para permitir la autonomía del sistema.
Interacción del Usuario: Comandos de activación (encendido/apagado) y parámetros de configuración (valor de altitud en msnm).

### 2. Salidas (Outputs)

| | las condiciones propias de zonas de altura como bajas temperaturas.
08/04/26 | D | Ergonomía: El uso del sistema en el usuario, la colocación de los electrodos y la interfaz de entrega de resultados deberán ser intuitivos y cómodos para el usuario. | Alejandra
08/04/26 | D | Costo: El diseño deberá considerar principalmente componentes accesibles y priorizar un sistema de bajo costo. | Juan
08/04/26 | E | Almacenamiento: El sistema podrá guardar los registros de las señales y permitir que pueda compartirse posteriormente. | Juan
08/04/26 | E | Visualización: El sistema deberá permitir la visualización clara de las señales procesadas en una pantalla TFT. | Brayamn

Información Procesada: Datos numéricos de las variables vitales, ajustados según el parámetro de altitud ingresado.
Visualización: Representación gráfica de las señales en tiempo real para verificar su calidad.
Estado Técnico: Información sobre la integridad de la conexión de los sensores y disponibilidad de energía.
Almacenamiento: Registro físico de la sesión clínica para consulta posterior.

### 3.2. Estructura de funciones

Funciones principales (Flujo de la señal):

1. Captar: Obtiene y mide las señales de las variables fisiológicas necesarias para el triaje.
2. Acondicionar: Filtra y amplifica la señal obtenida para mejorar su calidad.
3. Convertir: La información de las señales analógicas es convertida en datos digitales para su procesamiento digital.
4. Procesar: Análisis de los datos digitales mediante modelos matemáticos.
5. Almacenar: Guarda los datos del paciente para consultas posteriores.
6. Visualizar: El usuario puede observar las señales en tiempo real para monitoreo y toma de decisión.
7. Emitir: Realiza señal de “alerta” frente al ruido o mala posición de los electrodos.

### 8. Funciones secundarias: 9. Soporte energético

10. Transformar: Convierte la energía química de la batería en energía eléctrica.

### 11. Interacción del usuario

12. Presionar: Acción del usuario para indicar la activación y delimitar los parámetros de configuración.

Imagen 01: Estructura de funciones


### 4. Diseño de la Solución

### 4.1. Matriz Morfológica

Cuadro 1: Matriz morfológica


### 4.2. Evaluación y Selección de Alternativas

Cuadro 2: Clasificación de escala por puntaje

Puntaje | Significado en la escala de evaluación
5 | Excelente - cumple o supera el criterio sin restricciones
4 | Bueno - cumple el criterio con mínimas limitaciones aceptables
3 | Aceptable - cumple parcialmente el criterio con limitaciones notables
2 | Deficiente - cumple el criterio de forma insuficiente para el contexto
1 | Inaceptable - no cumple el criterio en el contexto a abordar

Cuadro 3: Evaluación de alternativas

Criterio | Peso | Solución 1 | Solución 2 | Solución 3
(p) | Punt. | Pond. | Punt. | Pond. | Punt. | Pond.
Costo | 0.30 | 3 | 0.90 | 5 | 1.50 | 2 | 0.60
Facilidad de implementación | 0.25 | 1 | 0.25 | 5 | 1.25 | 3 | 0.75
Precisión esperada | 0.25 | 4 | 1.00 | 4 | 1.00 | 4 | 1
Integración | 0.20 | 2 | 0.40 | 5 | 1.00 | 3 | 0.60
Puntaje total: | | 2.55 | | 4.75 | | 2.95

La solución 2 obtiene un puntaje ponderado total de 4.75 sobre 5.00, posicionándose ampliamente por encima de las alternativas 1 y 3. El único criterio en que la solución 2 no obtiene el máximo puntaje es el criterio de precisión esperada, dado que la plataforma Healthy Pi 5 opera en modo de investigación sin certificación clínica formal. Sin embargo, esta limitación es aceptable para el objetivo del proyecto.

En consecuencia, y siguiendo el procedimiento de evaluación y selección establecido por la norma VDI 2221, la solución 2 basada en la plataforma Healthy Pi 5 con procesamiento embebido, visualización TFT y almacenamiento en MicroSD se adopta como concepto de diseño definitivo para el desarrollo del sistema de triaje cardiopulmonar portátil para zonas rurales de altura.

### 4.3. Propuesta de Solución Final

### 4.3.1 Arquitectura completa:

La arquitectura del sistema propuesto se basa en un dispositivo portátil que integra sensores de ECG (MAX30001) para estimar la frecuencia cardíaca, respiratoria y actividad cardiaca en general, y de fotopletismografía (AFE4400) para medir la saturación de oxígeno y pulso, usando los módulos de Healthy Pi 5. La frecuencia respiratoria se obtiene del ECG mediante la neumografía por impedancia transtorácica [1].

Las señales fisiológicas obtenidas son acondicionadas mediante los módulos AFE y transmitidas al microcontrolador RP2040, el cual realiza el procesamiento embebido de las señales. Los resultados de estos parámetros pueden ser visualizados en una pantalla LCD TFT y almacenados en una tarjeta MicroSD, pero no cuentan con una conectividad inalámbrica.

Respecto a la alimentación, el sistema usa una batería recargable de Litio de 3.7 V y 2500 mAh. La interfaz de operación del sistema es intuitiva e integra botones físicos junto a un menú en la pantalla, mientras que su ergonomía considera que el dispositivo funciona como una caja portátil de escritorio. Para el post procesamiento de los datos, el sistema usa Python.

### 4.3.2 Justificación técnica:

La selección de la plataforma Healthy Pi 5 permite que el sistema pueda integrar múltiples sensores biomédicos, lo que reduce la complejidad del diseño y asegura que los módulos a usar sean compatibles. Los sensores integrados en plataforma permiten la obtención de las señales fisiológicas con una precisión suficiente para un triaje, que es la meta del proyecto. Además, la estimación de la frecuencia respiratoria mediante la neumografía por impedancia transtorácica permite evitar sensores adicionales, lo que reduce tanto el costo como el consumo energético.

El uso del microcontrolador RP2040 se justifica debido a su capacidad de procesamiento, arquitectura de doble núcleo y flexibilidad en sus interfaces de comunicación (SPI, I²C), además de ser parte de la plataforma Healthy Pi 5; esto lo hace adecuado para la implementación de un procesamiento embebido ideal para el contexto de uso, eliminando la necesidad de algún componente externo y priorizando su portabilidad y autonomía. La decisión de no incluir conectividad inalámbrica se justifica con la necesidad de garantizar la operatividad del sistema en entornos rurales, donde la red puede ser muy limitada, por ello, se prioriza el almacenamiento local mediante una tarjeta MicroSD.

La visualización en una pantalla TFT y el uso de botones físicos permite una interacción directa e intuitiva, adecuada para un personal de salud no especializado en un contexto de triaje donde se requiere un uso rápido y sencillo con el fin de minimizar la posibilidad de errores operativos. La alimentación basada en una batería recargable contribuye tanto a la portabilidad del sistema como a su autonomía, un factor esencial para zonas con posibles limitaciones en el acceso a energía eléctrica. El uso de Python para el post procesamiento fue seleccionado debido a su amplia disponibilidad de librerías para el procesamiento de señales y análisis de datos y permite implementar un análisis más avanzado de forma accesible.

### 4.3.3 Coherencia con la lista de exigencias:

La arquitectura final cumple con la exigencia de función principal y contexto de uso, integrando los componentes necesarios para obtener las señales de ECG, SpO2 y frecuencia respiratoria, además de tomar en cuenta las limitaciones propias del uso en zonas rurales de alturas. La solución propuesta resulta coherente con la lista de exigencias previamente establecidas, ya que el sistema permite adquirir, procesar y almacenar dichas señales mediante el uso de Healthy Pi 5 y sus sensores. La alimentación mediante una batería recargable cumple con la exigencia de energía, y garantiza la portabilidad y cierto grado de autonomía del sistema para la atención de múltiples pacientes. La visualización de los datos, almacenamiento e interfaz intuitiva toman en consideración tanto el contexto de uso como el usuario objetivo, facilitando el uso correcto del sistema. El diseño de la solución también integra las exigencias respecto a criterios de bajo costo, seguridad eléctrica y ergonomía, mediante la selección de la plataforma principal, la inclusión de alertas del estado técnico y el uso de baterías con un voltaje y amperaje por hora adecuados y seguros para el paciente.

### 4.4. Diagrama de Bloques de Hardware

Imagen 02: Diagrama de bloques de Hardware


El diseño de hardware del dispositivo de monitorización se estructura en dos zonas eléctricamente separadas para garantizar la seguridad del paciente y el estricto cumplimiento de la norma internacional IEC 60601-1-11. A continuación, se detalla la composición de los bloques y el flujo de los datos y la energía:

I. Zona Aislada de Paciente (Frontend Clínico)
Esta sección comprende los elementos en contacto directo con el paciente y los circuitos integrados de acondicionamiento primario. Opera con un plano de tierra independiente (AGND_iso).

Módulo ECG y Bioimpedancia: Los biopotenciales son capturados mediante electrodos de Ag/AgCl y dirigidos al circuito integrado especializado MAX30001. Este componente se encarga del acondicionamiento, filtrado analógico y conversión analógico-digital (ADC) de las señales de actividad cardíaca y de la frecuencia respiratoria (mediante medición de impedancia transtorácica).

Módulo de Oximetría (SpO2): La señal de fotopletismografía (PPG) es capturada por un sensor óptico tipo clip de dedo. Esta señal es procesada por el chip AFE4400, el cual controla la emisión de los LEDs (infrarrojo y rojo), amplifica la respuesta del fotodiodo y digitaliza la señal resultante.

Alimentación Aislada: Un regulador LDO (Low Dropout) de ultra bajo ruido recibe energía a través de la barrera galvánica y provee voltajes estables y seguros a los chips MAX30001 y AFE4400 [1].

II. Barrera de Aislamiento Galvánico
Para evitar el paso de corrientes de fuga desde la red eléctrica hacia el paciente, se implementa una separación física y electrónica absoluta entre el frontend clínico y la placa principal:

Aislamiento de Datos: Las señales digitalizadas en formato SPI (provenientes de los chips frontales) cruzan la barrera a través de aisladores digitales de alta velocidad. Esto permite una transmisión de datos robusta sin contacto eléctrico.

Aislamiento de Energía: La potencia requerida por la zona del paciente cruza la barrera mediante un convertidor DC-DC aislado (ej. B0505S-1W), el cual transfiere la energía magnéticamente.

III. Zona de Control y Procesamiento (Placa Principal)
Esta sección no aislada gestiona la lógica central del sistema, el procesamiento de señales, el almacenamiento local y la interfaz de usuario.

Unidad Central de Procesamiento (MCU RP2040): El microcontrolador principal del sistema Healthy Pi 5 recibe las señales SPI aisladas. Se encarga de ejecutar los algoritmos de Procesamiento Digital de Señales (DSP), calcular las constantes vitales (FC, FR, SpO2) y aplicar los modelos matemáticos de corrección por altitud, fundamentales para el triaje en zonas rurales y de montaña.

Interfaz de Usuario y Visualización: El RP2040 renderiza las formas de onda y los valores numéricos calculados en tiempo real sobre una pantalla LCD TFT integrada (comunicación vía SPI). La interacción y navegación por los menús se realiza a través de un arreglo de botones físicos conectados a los puertos GPIO.

Almacenamiento Seguro: Para garantizar la integridad de los datos clínicos en zonas con escasa o nula conectividad a internet, el sistema omite módulos de transmisión inalámbrica y registra el historial en un módulo de tarjeta MicroSD de forma local.

IV. Sistema de Gestión de Energía Dual
El bloque de potencia está diseñado para asegurar una operatividad continua frente a la inestabilidad de la infraestructura eléctrica en zonas rurales:

Alimentación de Red Principal: El dispositivo cuenta con una entrada para tomacorrientes estándar peruano (220V AC, Tipo C/L). Esta tensión es acondicionada por un convertidor AC-DC de grado médico, garantizando una reducción de voltaje segura.

Alimentación Autónoma: El sistema integra un circuito de gestión de carga y una batería recargable de Ion de Litio (3.7V, 2500mAh). La batería proporciona energía a la placa principal, a los periféricos y al convertidor DC-DC aislado, asegurando el funcionamiento autónomo del equipo durante cortes de energía o traslados de pacientes [1].

### 5. Implementación y Experiencia de Usuario 5.1. Boceto del Sistema


### 5.2. Escenario de Uso Real

### 5.2.1. Perfil del usuario

Personal técnico de salud: Principalmente técnicos en enfermería encargados de realizar la evaluación fisiológica inicial mediante el triaje cardiopulmonar.
Personal de salud no especializado: Profesionales en puestos de salud de primer nivel que no cuentan con especialidad en cardiología o neumología. Paciente: Pobladores de zonas rurales altoandinas que acuden por chequeos preventivos o síntomas de mal de altura.

### 5.2.2. Entorno físico

Puestos de salud de primer nivel: Establecimientos rurales (postas y centros de salud) ubicados en zonas de gran altitud, considerando aquellos a más de 3,500 msnm.
Entornos con condiciones críticas: Entornos con hipoxia hipobárica (baja presión de oxígeno), clima frío que afecta la perfusión periférica, falta de conectividad estable y suministro eléctrico intermitente o inexistente
5.2.3. Secuencia desde el encendido hasta la obtención de resultados.
1. Encendido y autonomía: El personal enciende el dispositivo, el cual opera con baterías internas recargables, garantizando autonomía en zonas sin red eléctrica estable.

### 2. Preparación del paciente y colocación de sensores:

1. Se colocan tres electrodos en el tórax del paciente para captar el electrocardiograma (ECG) y la frecuencia respiratoria (FR).
2. Se coloca el sensor de clip (oxímetro) en el dedo para medir la saturación de oxígeno (SpO2) y el pulso.

### 3. Adquisición y Procesamiento: Los chips especializados

(AFE4400 y MAX30001) digitalizan las señales biológicas, mientras el microcontrolador filtra el ruido (como el causado por el frío) y calcula las variables en tiempo real.
4. Visualización de resultados: La información (ECG, FC, SpO2 y FR) se muestra de forma clara en una pantalla TFT integrada, sin necesidad de computadoras externas.

### 5. Registro y almacenamiento: Los resultados se guardan

automáticamente en una tarjeta MicroSD local para permitir auditorías médicas posteriores o el seguimiento del paciente.

### 6. Bibliografía

[1] A. Whitchurch, “HealthyPi 5,” Crowd Supply, 4 de marzo de 2024. [En línea]. Disponible en: https://www.crowdsupply.com/protocentral/healthypi-5. [Accedido: 17 de abril de 2024]

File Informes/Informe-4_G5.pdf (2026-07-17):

## UNIVERSIDAD PERUANA CAYETANO HEREDIA

## INGENIERÍA BIOMÉDICA


# PRÁCTICA DE INSTRUMENTACIÓN BIOMÉDICA

## Solución final y componentes del prototipo

## [Práctica N°4]

GRUPO N°: 5

Nombre de los Integrantes y código:

# - Aldo David, Manturano Lopez - 72387388 - David Eddy, Aguilar Yahuana - 71421807 - Juan Raul, Ramirez Mendoza - 72642526 - Alejandra Ivonne, Gamarra Leyva - 72771921 - Davidt Brayamn, Fernandez Bernaola - 72165022 - Gustavo Andre, Ruiz Ortiz - 72899306

2026 -1

### 1. Integracion de resultados

### 1.1. Problema clínico definido

La evaluación del estado cardiopulmonar en zonas rurales altoandinas se ve

obstaculizada por la falta de equipos biomédicos adaptados a la fisiología de

altura y la escasez de personal especialista. Los dispositivos de monitoreo

convencionales están calibrados para el nivel del mar, lo que genera falsas

alarmas fisiológicas de salud en el momento de triaje cardiopulmonar de la

comunidad, además de depender de infraestructura eléctrica o conectividad

inexistente.

### 1.2. Variables fisiológicas seleccionadas

Monitoreamos la saturación de oxígeno, frecuencia respiratoria y frecuencia

cardiaca.

### 1.3. Señales biomédicas identificadas

1.3.1. Electrocardiograma (ECG)
1.3.1.1. El ECG es adquirido por el chip MAX30001 el cual es un AFE

(Analog Front End) que detecta las diferencias de potencial

eléctrico generadas por la despolarización y repolarización del

músculo cardíaco a través de electrodos de superficie

colocados en el tórax del paciente.

1.3.2. Señal de fotopletismografía (PPG)
1.3.2.1. La señal de SpO2 es capturada mediante un sensor óptico

externo y procesada por el chip AFE4400, que actúa como el

Front-End Analógico (AFE) del sistema, permitiendo convertir

los datos analógicos en datos digitales precisos, permitiendo

así el cálculo de la saturación de oxígeno por parte del

procesador central [1]

1.3.3. Frecuencia respiratoria (FR)
1.3.3.1. La Frecuencia Respiratoria (FR) se obtiene como señal

derivada del ECG mediante la técnica de Neumografía por

Impedancia Transtorácica. Esta técnica no requiere sensores

adicionales: utiliza los mismos tres electrodos del ECG para

medir los cambios en la impedancia eléctrica del tórax

provocados por el ciclo respiratorio.

Se desarrolló y validó con éxito un sistema de monitoreo

ergonómico, integrado en una camiseta, capaz de registrar

parámetros fisiológicos de forma no invasiva en condiciones

extremas de alta montaña. El sistema utiliza neumografía por

impedancia para determinar la frecuencia respiratoria midiendo

las variaciones de volumen de aire en los pulmones a través de

la impedancia torácica. Los resultados demostraron que el

dispositivo es altamente eficaz, logrando una estimación de la

frecuencia respiratoria con un error clínico insignificante (≤

±3)en el 83% de las muestras promedio. Por lo tanto, se valida

que la técnica de Neumografía por Impedancia Transtorácica

puede usarse en zonas rurales de altura que alcanzan valores

de hasta 3000 msnm o mayor [2].

### 1.4. Señales fisiológicas afectadas por la altura

Se realizó pruebas en el Perú a alturas de 3827–4348 msnm, indicando que la

altitud extrema en la región de Puno altera significativamente los valores

basales de los niños sanos, elevando la frecuencia respiratoria (RR) y

reduciendo la saturación de oxígeno (SpO2) de forma natural como respuesta

a la menor presión parcial de oxígeno en el ambiente. Mientras que niños en

zonas de baja altitud como India presentan una RR media de 31.9

respiraciones por minuto y una SpO2 de 98.3%, los niños peruanos muestran

promedios de 48.0 respiraciones por minuto y 89.7% de saturación. Este

fenómeno se evidencia visualmente en la Figura 1, donde los datos de Perú

se agrupan sistemáticamente en la parte superior del gráfico de RR y en la

base del gráfico de SpO2 en comparación con los otros países. Esto justifica

que las señales fisiológicas a atender en el proyecto serán afectadas por la

altitud donde se ubican las comunidades de zonas rurales, asimismo,

esclarece en lo que se debe de trabajar para obtener datos viables [3].


Figura 1: Frecuencia respiratoria media y saturación de oxígeno (SpO₂) por

edad en meses, estratificadas por centro [3]

### 1.5. Interpretación de las señales en función de la altitud

Existe una necesidad de interpretar las señales fisiológicas afectadas por la

altura, como lo son la saturación de oxígeno (SpO2) y la frecuencia respiratoria

(RR), respecto al contexto para otorgar una información correcta que influirá

en la toma de decisión clínica. Para ello, primero se investigó un estudio en el

que se registraron los valores de SpO2 de 53 montañeros que participaron en

actividades de alta montaña. Con estos valores, se creó un modelo de

regresión lineal múltiple para la estimación de SpO2 con respecto a la altitud,

obteniendo la siguiente ecuación: SpO2 estimada = 103.3 – (altitud× 0,0047)

+ (Z), siendo Z = 0,7 en hombres y 1,4 en mujeres. [4]


Figura 2: Valores de saturación arterial de oxígeno de los casos de mal de

altura grave en relación con los límites de normalidad [4]

Sin embargo, el modelo y la ecuación planteada en el estudio solo responde

cuál sería la saturación de oxígeno esperada de una persona sana a cierta

altura sobre el nivel del mar, por lo que no es posible usarla para interpretar

mediciones reales en poblaciones que viven en zonas de gran altitud.

Por ello, se decidió usar un método alternativo basado en el análisis de

percentiles de SpO2 obtenidos de estudios poblacionales en diferentes

altitudes. En particular, se emplearán los percentiles reportados en un estudio

de valores de referencia de SpO2 en personas aclimatadas, desde el nivel del

mar hasta altitudes correspondientes a asentamientos en Puno [5]. De esta

manera, el valor medido podrá compararse con la distribución poblacional

esperada, permitiendo una interpretación más adecuada del estado fisiológico

del paciente dentro de su contexto ambiental.


Figura 3: Percentiles 2.5, 10, 25, 50, 75, 90 y 97.5 de SpO2 para todos los

sujetos en función de la altitud. [5]

### 1.6. Ruta técnica del flujo general de la señal

Esta ruta corresponde al sistema desplegado en el puesto de salud rural, este

diseño elimina toda dependencia de infraestructura externa con el objetivo de

presentar autonomía en zonas remotas y simplicidad operativa en el triaje del

paciente. Componentes de la ruta:

I. Adquisición de señales
II. | Procesamiento embebido
III. | Visualización en pantalla TFT
IV. | Registro local MicroSD
V. Post-procesamiento MicroSD

El procesamiento embebido en la placa y la visualización en pantalla TFT

elimina la dependencia de un PC o conexión a internet, esto garantiza que el

equipo sea portátil y operativo en cualquier puesto de salud de primer nivel.

### 2. Lista de exigencias

Fecha | Deseo o exigencia | Descripción | Responsable
08/04/26 | E | Función principal: Adquirir, procesar, visualizar y almacenar señales de ECG, SpO2 y frecuencia respiratoria para triaje cardiopulmonar en tiempo real. | Todos
08/04/26 | E | Usuario objetivo: Personal técnico de salud (técnicos en enfermería) que realice la evaluación fisiológica inicial mediante el triaje cardiopulmonar y personal de salud variado que se encuentre en los puestos de salud de primer nivel. | Todos
08/04/26 | E | Contexto de uso: Uso hospitalario, el sistema va a funcionar en puestos de salud de primer nivel rurales y de altura, considerando recursos limitados, posibles fallas en la electricidad, barreras de lenguaje y falta de personal especializado. | Todos
08/04/26 | E | Señal a medir: Entrada: Biopotenciales de superficie captados mediante electrodos, señales de fotopletismografía (PPG) mediante un sensor. Salida: Señal ECG visualizable, frecuencia cardíaca estimada, saturación de oxígeno, frecuencia respiratoria como señal derivada del ECG y registro de datos. | Brayamn, David
08/04/26 | E | Precisión esperada: Las señales adquiridas deberán tener una calidad suficiente y un buen manejo del ruido para estimar las variables de frecuencia cardíaca, frecuencia respiratoria y saturación de oxígeno de manera confiable. El sistema deberá estimar la frecuencia cardíaca con un error máximo de ±3 bpm; la frecuencia respiratoria con ±2 rpm y el SpO2 con un error máximo de ±2%. | Alejandra, Aldo
08/04/26 | E | Portabilidad: El sistema debe ser liviano y resistente, de uso portátil y fácil de transportar de forma segura, considerando que será usado en zonas alejadas del país para permanecer como un equipo de evaluación puntual. | Gustavo
08/04/26 | E | Energía: El sistema deberá funcionar mediante alimentación interna por baterías recargables. | David, Juan
08/04/26 | E | Autonomía: La duración del sistema de triaje es de 17 horas antes de necesitar una recarga de batería. El tiempo estimado por sesión de triaje es de 5 minutos, con un aproximado de 200 sesiones por recarga del dispositivo. | Alejandra
08/04/26 | E | Electrónica: El sistema usará la plataforma Healthy Pi 5, el MAX30001 Y el AFE4400 para la | Gustavo, Alejandra

### 3. Arquitectura Funcional del Sistema

3.1. Diagrama de Caja Negra


Figura 4: Caja negra del sistema

### 3.2. Estructura de funciones

3.2.1. Funciones principales (Flujo de la señal)
1. Captar: Obtiene y mide las señales de PPG y ECG para el triaje.
2. Acondicionar: Filtra y amplifica la señal obtenida para mejorar

su calidad.

| | adquisición de las señales.
08/04/26 | E | Seguridad: El sistema deberá trabajar de acuerdo a la normativa de seguridad eléctrica IEC 60601-1-11, con niveles seguros de alimentación y un factor de corrección adecuado para evitar riesgo eléctrico. Además, los componentes del sistema deberán soportar caídas sobre superficies duras y las condiciones propias de zonas de altura como bajas temperaturas. | Aldo, Juan
08/04/26 | D | Ergonomía: El uso del sistema en el usuario, la colocación de los electrodos y la interfaz de entrega de resultados deberán ser intuitivos y cómodos para el usuario. | Alejandra
08/04/26 | D | Costo: El diseño deberá considerar principalmente componentes accesibles y priorizar un sistema de bajo costo. | Juan
08/04/26 | E | Almacenamiento: El sistema podrá guardar los registros de las señales y permitir que pueda compartirse posteriormente. | Juan
08/04/26 | E | Visualización: El sistema deberá permitir la visualización clara de las señales procesadas en una pantalla TFT. | Brayamn

3. Convertir: La información de las señales analógicas es

convertida en datos digitales para su procesamiento digital.

4. Procesar: Análisis de los datos digitales mediante modelos

matemáticos.

5. Almacenar: Guarda los datos del paciente para consultas

posteriores.

6. Visualizar: El usuario puede observar las señales en tiempo real

para monitoreo y toma de decisión.

7. Emitir: Realiza señal de “alerta” frente al ruido o mala posición

de los electrodos.

3.2.2. Funciones secundarias
1. Soporte energético
2. Transformar: Convierte la energía química de la batería en

energía eléctrica.

3. Interacción del usuario
4. Presionar: Acción del usuario para indicar la activación y

delimitar los parámetros de configuración.


Figura 5: Estructura de funciones

### 4. Diseño de la Solución

### 4.1. Matriz Morfológica

Cuadro 1: Matriz morfológica


El concepto de solución 2 representa el equilibrio óptimo entre robustez técnica

y facilidad de uso en el campo, superando las limitaciones de las otras

alternativas. A diferencia del Concepto 1, que depende de una PC y software

Open, la solución 2 garantiza autonomía total mediante procesamiento

embebido y una pantalla TFT. Por otro lado, frente al concepto 3, que propone

un diseño wearable y conectividad Wi-Fi/Nube, la solución 2 es superior para

el contexto de triaje rápido, ya que evita la inestabilidad de las redes

inalámbricas en zonas de altura.

Al optar por una caja portátil con registro en MicroSD, el concepto 2 asegura

que los datos se guarden de forma segura y física, permitiendo una

interpretación inmediata mediante una interfaz de botones y un post-

procesamiento universal en Python, lo cual es mucho más práctico para el

traslado de pacientes hacia hospitales de mayor nivel que depender de una

infraestructura de red inexistente.

### 4.2. Evaluación y Selección de Alternativas

Cuadro 2: Clasificación de escala por puntaje

Puntaje | Significado en la escala de evaluación
5 | Excelente - cumple o supera el criterio sin restricciones
4 | Bueno - cumple el criterio con mínimas limitaciones aceptables
3 | Aceptable - cumple parcialmente el criterio con limitaciones notables
2 | Deficiente - cumple el criterio de forma insuficiente para el contexto
1 | Inaceptable - no cumple el criterio en el contexto a abordar

Cuadro 3: Justificación de criterios

Criterios | Justificación

Costo | Los puestos de salud de primer nivel en zonas rurales operan con presupuestos extremadamente limitados.
Facilidad de implementación | El equipo será operado por personal técnico de salud y la interfaz debe permitir triaje inmediato sin curva de aprendizaje compleja.
Precisión esperada | La fiabilidad de las señales adquiridas determina la calidad del triaje.
Integración | La capacidad de adquirir múltiples señales fisiológicas desde una única plataforma reduce el error de triaje.

Cuadro 4: Evaluación de alternativas

Criterio | Peso | Solución 1 | Solución 2 | Solución 3
(p) | Punt. | Pond. | Punt. | Pond. | Punt. | Pond.
Costo | 0.30 | 3 | 0.90 | 5 | 1.50 | 2 | 0.60
Facilidad de implementación | 0.25 | 1 | 0.25 | 5 | 1.25 | 3 | 0.75
Precisión esperada | 0.25 | 4 | 1.00 | 4 | 1.00 | 4 | 1
Integración | 0.20 | 2 | 0.40 | 5 | 1.00 | 3 | 0.60
Puntaje total: | | 2.55 | | 4.75 | | 2.95

La solución 2 obtiene un puntaje ponderado total de 4.75 sobre 5.00,

posicionándose ampliamente por encima de las alternativas 1 y 3. El único

criterio en que la solución 2 no obtiene el máximo puntaje es el criterio de

precisión esperada, dado que la plataforma Healthy Pi 5 opera en modo de

investigación sin certificación clínica formal. Sin embargo, esta limitación es

aceptable para el objetivo del proyecto.

En consecuencia, y siguiendo el procedimiento de evaluación y selección

establecido por la norma VDI 2221, la solución 2 basada en la plataforma

Healthy Pi 5 con procesamiento embebido, visualización TFT y

almacenamiento en MicroSD se adopta como concepto de diseño definitivo

para el desarrollo del sistema de triaje cardiopulmonar portátil para pobladores

de zonas rurales altoandinas que acuden por chequeos preventivos.

### 4.3. Solución Final Propuesta

### 4.3.1 Arquitectura completa:

La arquitectura del sistema propuesto se basa en un dispositivo portátil que

integra sensores de ECG (MAX30001) para estimar la frecuencia cardíaca,

respiratoria y actividad cardiaca en general, y de fotopletismografía (AFE4400)

para medir la saturación de oxígeno y pulso, usando los módulos de Healthy

Pi 5. La frecuencia respiratoria se obtiene del ECG mediante la neumografía

por impedancia transtorácica [1].

Las señales fisiológicas obtenidas son acondicionadas mediante los módulos

AFE y transmitidas al microcontrolador RP2040, el cual realiza el

procesamiento embebido de las señales. Los resultados de estos parámetros

pueden ser visualizados en una pantalla LCD TFT y almacenados en una

tarjeta MicroSD, pero no cuentan con una conectividad inalámbrica.

Respecto a la alimentación, el sistema usa una batería recargable de Litio de

3.7 V y 2500 mAh. La interfaz de operación del sistema es intuitiva e integra

botones físicos junto a un menú en la pantalla, mientras que su ergonomía

considera que el dispositivo funciona como una caja portátil de escritorio. Para

el post procesamiento de los datos, el sistema usa Python.

### 4.3.2 Objetivo del sistema

El objetivo principal del sistema propuesto es adquirir y procesar las señales

relevantes establecidas de ECG, SpO2 y frecuencia respiratoria para

proporcionar un sistema de triaje cardiopulmonar que se pueda adaptar a las

condiciones de un puesto de salud rural en zonas de altura y pueda ser usado

por los pobladores del lugar para triajes rápidos y chequeos preventivos.

### 4.3.3 Función principal

La función principal es adquirir, procesar, visualizar y almacenar señales de

ECG, SpO2 y frecuencia respiratoria para triaje cardiopulmonar en tiempo real.

### 4.3.4 Usuario final

Usuario operario: Personal técnico de salud que realice la evaluación

fisiológica inicial mediante el triaje cardiopulmonar y personal de salud que se

encuentre en los puestos de salud de primer nivel.
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

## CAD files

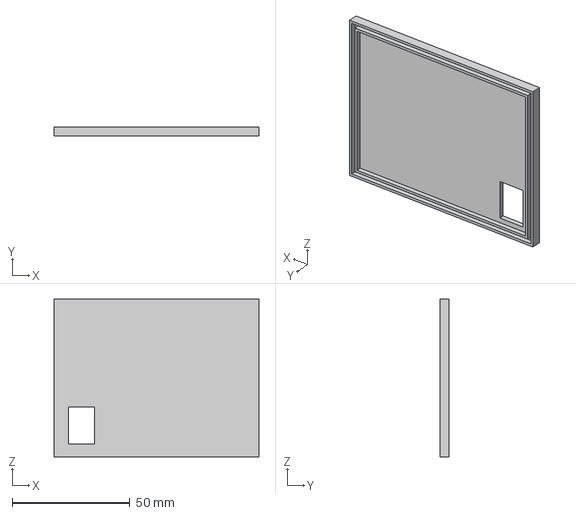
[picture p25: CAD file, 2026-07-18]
Modelado-3D/Enclosure_tapa.step
87.2 x 4.00 x 67.2 mm

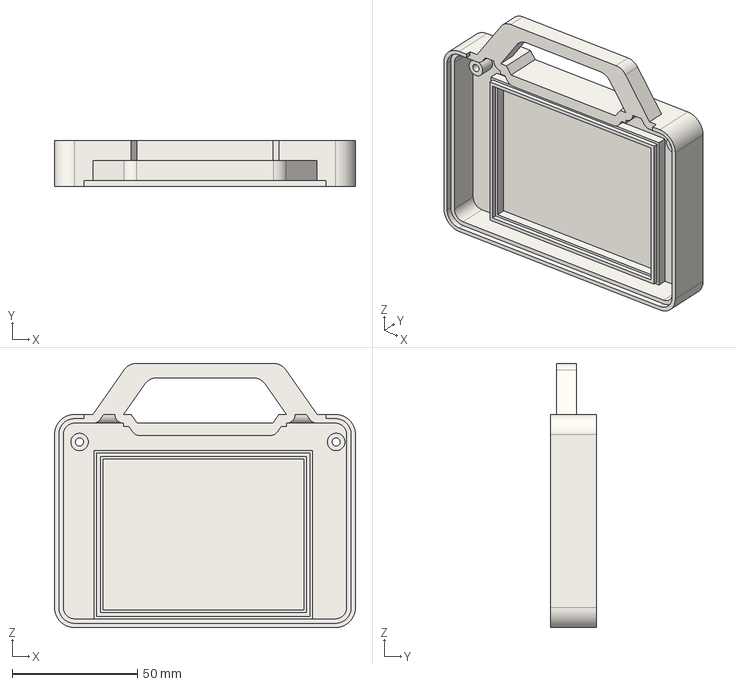
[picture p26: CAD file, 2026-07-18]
Modelado-3D/Enclosure_parte2.step
120.0 x 18.5 x 105.3 mm

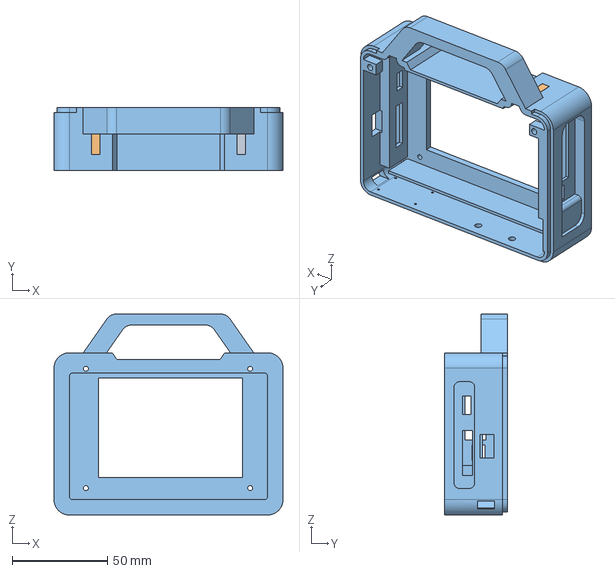
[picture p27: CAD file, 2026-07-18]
Modelado-3D/Enclosure_parte1.step
120.0 x 33.0 x 105.3 mm

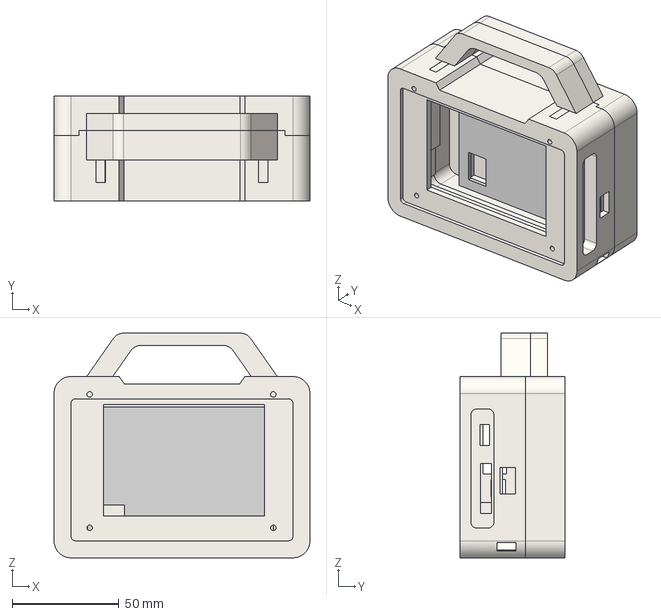
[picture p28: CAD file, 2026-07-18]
Modelado-3D/Enclosure_completo_step.step
120.0 x 49.0 x 105.3 mm

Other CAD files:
Modelado-3D/Enclosure_completo_f3d.f3d

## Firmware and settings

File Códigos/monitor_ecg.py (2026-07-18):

import matplotlib
matplotlib.use('Qt5Agg')

import signal
signal.signal(signal.SIGINT, signal.SIG_DFL)

import serial
import numpy as np
import matplotlib.pyplot as plt
import matplotlib.animation as animation
from collections import deque
import struct
import threading
import csv
import os
from datetime import datetime

# ============================================================
# CONFIGURACIÓN
# ============================================================
PORT        = 'COM14'
BAUD        = 115200
FS          = 128
WINDOW_SECS = 6
BUFFER_SIZE = FS * WINDOW_SECS

# ============================================================
# CSV — archivo nuevo por cada sesión
# ============================================================
csv_filename = f"healthypi_{datetime.now().strftime('%Y%m%d_%H%M%S')}.csv"
csv_folder   = r"C:\Users\Administrador 1\Desktop\Presentación fianal"
os.makedirs(csv_folder, exist_ok=True)
csv_filepath = os.path.join(csv_folder, csv_filename)
csv_file     = open(csv_filepath, 'w', newline='', encoding='utf-8')
csv_writer   = csv.writer(csv_file)
csv_writer.writerow(['timestamp', 'ecg_raw', 'ecg_filtrado',
                     'bioz', 'ppg_ir', 'hr_bpm', 'rr_rpm',
                     'spo2_pct', 'altitud_m', 'estado_spo2'])
print(f"Guardando datos en: {csv_filepath}")

# ============================================================
# TABLA DE PERCENTILES SpO2 vs ALTITUD
# Fuente: Rojas-Camayo et al., Thorax 2018
# Columnas: altitud_m, p2_5, p10, p25, p75, p97_5
# ============================================================
SPO2_TABLA = [
    (    0,  95,  96,  97,  99, 100),
    (  500,  94,  95,  97,  99, 100),
    ( 1000,  93,  95,  96,  98,  99),
    ( 1500,  92,  94,  95,  98,  99),
    ( 2000,  90,  92,  94,  97,  98),
    ( 2500,  88,  90,  92,  96,  98),
    ( 3000,  85,  88,  91,  95,  97),
    ( 3500,  82,  85,  88,  93,  96),
    ( 4000,  78,  82,  86,  91,  94),
    ( 4500,  74,  78,  83,  89,  93),
    ( 5000,  70,  75,  80,  87,  91),
]

def interpolar_percentiles(alt_m):
    """Interpola percentiles SpO2 para una altitud dada."""
    if alt_m <= SPO2_TABLA[0][0]:
        return SPO2_TABLA[0][1:]
    if alt_m >= SPO2_TABLA[-1][0]:
        return SPO2_TABLA[-1][1:]
    for i in range(len(SPO2_TABLA) - 1):
        a0, *p0 = SPO2_TABLA[i]
        a1, *p1 = SPO2_TABLA[i+1]
        if a0 <= alt_m < a1:
            frac = (alt_m - a0) / (a1 - a0)
            return tuple(int(p0[j] + frac * (p1[j] - p0[j])) for j in range(5))
    return SPO2_TABLA[-1][1:]

def evaluar_spo2(spo2, alt_m):
    """Devuelve etiqueta de estado según percentil poblacional."""
    if alt_m < 0:
        return "SIN DATO"
    p2_5, p10, p25, p75, p97_5 = interpolar_percentiles(alt_m)
    if spo2 < p2_5:  return "CRITICO"
    if spo2 < p10:   return "BAJO"
    if spo2 < p25:   return "NORMAL-BAJO"
    if spo2 <= p75:  return "NORMAL"
    return "NORMAL-ALTO"

# Presión de referencia al nivel del mar (Pa)
PRESION_NM = 101325.0

def calcular_altitud(presion_hpa):
    """Fórmula barométrica ISA: altitud en metros desde presión en hPa."""
    presion_pa = presion_hpa * 100.0
    return 44330.0 * (1.0 - (presion_pa / PRESION_NM) ** (1.0 / 5.255))

# ============================================================
# FILTROS IIR MANUALES (sin scipy)
# ============================================================
class NotchFilter:
    def __init__(self, fs=128, f0=60, Q=30):
        w0    = 2 * np.pi * f0 / fs
        alpha = np.sin(w0 / Q) / 2
        a0    = 1 + alpha
        self.b = [1/a0, -2*np.cos(w0)/a0, 1/a0]
        self.a = [1,    -2*np.cos(w0)/a0, (1-alpha)/a0]
        self.x1 = self.x2 = self.y1 = self.y2 = 0.0

    def process(self, x):
        y = (self.b[0]*x + self.b[1]*self.x1 + self.b[2]*self.x2
             - self.a[1]*self.y1 - self.a[2]*self.y2)
        self.x2 = self.x1; self.x1 = x
        self.y2 = self.y1; self.y1 = y
        return y

class BandpassFilter:
    def __init__(self, fs=128, low=0.5, high=40.0):
        w    = 2 * np.pi * low / fs
        k    = np.tan(w / 2)
        norm = 1 / (1 + np.sqrt(2)*k + k*k)
        self.b1 = [norm, -2*norm, norm]
        self.a1 = [1, 2*(k*k-1)*norm, (1-np.sqrt(2)*k+k*k)*norm]
        w = 2 * np.pi * high / fs
        k = np.tan(w / 2)
        d = 1 + np.sqrt(2)*k + k*k
        self.b2 = [k*k/d, 2*k*k/d, k*k/d]
        self.a2 = [1, 2*(k*k-1)/d, (1-np.sqrt(2)*k+k*k)/d]
        self.x1_1=self.x2_1=self.y1_1=self.y2_1=0.0
        self.x1_2=self.x2_2=self.y1_2=self.y2_2=0.0

    def process(self, x):
        y1 = (self.b1[0]*x  + self.b1[1]*self.x1_1 + self.b1[2]*self.x2_1
              - self.a1[1]*self.y1_1 - self.a1[2]*self.y2_1)
        self.x2_1=self.x1_1; self.x1_1=x
        self.y2_1=self.y1_1; self.y1_1=y1
        y2 = (self.b2[0]*y1 + self.b2[1]*self.x1_2 + self.b2[2]*self.x2_2
              - self.a2[1]*self.y1_2 - self.a2[2]*self.y2_2)
        self.x2_2=self.x1_2; self.x1_2=y1
        self.y2_2=self.y1_2; self.y1_2=y2
        return y2

notch = NotchFilter()
bpf   = BandpassFilter()

# ============================================================
# BUFFERS
# ============================================================
ecg_raw  = deque([0]*BUFFER_SIZE, maxlen=BUFFER_SIZE)
ecg_filt = deque([0]*BUFFER_SIZE, maxlen=BUFFER_SIZE)
ppg_buf  = deque([0]*BUFFER_SIZE, maxlen=BUFFER_SIZE)
bioz_buf = deque([0]*BUFFER_SIZE, maxlen=BUFFER_SIZE)

hr_value     = [0]
spo2_value   = [0]
rr_value     = [0]
alt_value    = [-1.0]   # -1 = sin dato aún
estado_value = ["--"]

running = True

# ============================================================
# PARSER — Formato legacy OpenView (tipo 0x02, 22 bytes)
# [0-3]  ECG int32  [4-7]  BioZ int32  [8] skip
# [9-12] Red int32  [13-16] IR int32
# [17-18] temp      [19] spo2  [20] hr  [21] rr
# ============================================================
def parse_legacy_packet(payload):
    if len(payload) < 22:
        return None
    try:
        ecg  = struct.unpack('<i', bytes(payload[0:4]))[0]
        bioz = struct.unpack('<i', bytes(payload[4:8]))[0]
        red  = struct.unpack('<i', bytes(payload[9:13]))[0]
        ir   = struct.unpack('<i', bytes(payload[13:17]))[0]
        spo2 = payload[19]
        hr   = payload[20]
        rr   = payload[21]
        return ecg, bioz, red, ir, hr, rr, spo2
    except:
        return None

# ============================================================
# PARSER — Paquete de altitud (tipo 0x05, 4 bytes)
# int32 little-endian en centímetros (alt_cm = altitud_m * 100)
# Definido en data_module.c: CES_CMDIF_TYPE_ALTITUDE_DATA / send_altitude_packet()
# ============================================================
def parse_altitude_packet(payload):
    if len(payload) < 4:
        return None
    try:
        alt_cm = struct.unpack('<i', bytes(payload[0:4]))[0]
        return alt_cm / 100.0
    except:
        return None
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
